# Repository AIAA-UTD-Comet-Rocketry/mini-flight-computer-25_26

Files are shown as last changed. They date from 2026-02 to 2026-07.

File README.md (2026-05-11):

# ESP32 Mini Flight Computer 25-26

Firmware for comet rocketry's flight computer built on the ESP32-S3 platform. The system handles sensor fusion, barometric altimetry, flight state management, pyrotechnic deployment, SD card logging, and CAN bus telemetry.

---

## Prerequisites

- ESP-IDF v5.5.x — [Official Installation Guide](https://docs.espressif.com/projects/esp-idf/en/latest/esp32/get-started/index.html)
- VSCode with the ESP-IDF extension (recommended) or any IDE with C/C++ support
- ESP32-S3 board to flash firmware

Build and flash:
```
idf.py build
idf.py erase-flash
idf.py flash monitor
```

---

## Hardware

**Microcontroller:** ESP32-S3

### Sensors (I2C)

| Sensor | Bus | Address | Function |
|---|-----|---|---|
| LSM6DSV80X | I2C0 (SDA=39, SCL=40) | 0x6A | 6-axis IMU — ±80g accelerometer + gyroscope |
| LPS22DF | I2C1 (SDA=41, SCL=42) | 0x5C | Barometric pressure / temperature |
| IIS2MDC | I2C1 (SDA=41, SCL=42) | 0x1E | 3-axis magnetometer |

### GPIO Pinout

| Function | GPIO |
|---|---|
| Pyro — Drogue 1 (35g CO2) | 6 |
| Pyro — Drogue 2 (45g CO2) | 7 |
| Pyro — Main 1 | 8 |
| Pyro — Main 2 | 9 |
| LED — Status | 1 |
| LED — CAN TX | 2 |
| LED — CAN RX | 4 |
| LED — SD TX | 10 |
| LED — SD RX | 11 |
| CAN RX (TWAI) | 36 |
| CAN TX (TWAI) | 37 |
| IMU INT1 | 38 |
| Baro INT | 46 |
| SD CLK | 34 |
| SD CMD | 47 |
| SD DATA0-3 | 48, 35, 21, 26 |

---

## Software Architecture

The firmware runs on FreeRTOS with five concurrent tasks at 100 Hz each. All sensor data is funnelled into a shared `FusedPacket_t` struct protected by a spinlock.

```
app_main()
│
├── BSP init (I2C, sensors, CAN, GPIO)
├── IMU calibration (NVS-backed, auto-sequence on first run)
├── Ground pressure calibration (1 s average)
│
├── Task: vImuHandlerTask    priority 2 — reads LSM6DSV80X, runs Madgwick AHRS
├── Task: vAltHandlerTask    priority 2 — reads LPS22DF, IIR filters pressure, computes altitude
├── Task: vFsmTask           priority 2 — runs flight state machine at 10 ms
├── Task: vSdLoggerTask      priority 1 — writes CSV to SD card at 100 ms
├── Task: LED_Task           priority 0 — drives LED blink patterns
├── Task: Pyro_Task          priority 4 — fires pyro channels on task notification
└── Task: CAN-TLM            priority 1 — broadcasts CANaerospace telemetry
```

### Sensor Pipeline

```
LSM6DSV80X (raw mg, mdps)
  └─► apply NVS calibration (offset + sensitivity)
  └─► axis remap (BOARD_AXIS_ALIGNMENT)
  └─► FusionBias (gyro bias estimation)
  └─► Madgwick AHRS (quaternion → Euler angles, earth-frame acceleration)
  └─► sensor_velocity_predict() (accel integration → vertical velocity)
  └─► FusedPacket_t { currAcc, currGyro, orientation, linearAcc, gTotalAcc }

LPS22DF (raw hPa)
  └─► hardware LPF at ODR/9 + 64-sample averaging (on-chip)
  └─► sensor_pressure_filter() — 2nd-order Butterworth IIR, fc=5 Hz
  └─► sensor_get_altitude() — ISA pressure-altitude formula (ft MSL)
  └─► sensor_velocity_correct() — complementary filter blends baro Δalt/Δt with accel velocity
  └─► FusedPacket_t { currPress, currTempF, gAltitude, gVerticalVelocity }
```

Calibration parameters (accel offset, accel sensitivity, gyro offset) are stored in NVS and loaded on boot. Re-running calibration requires enabling the `calibration_run_menu()` call in `app_main()`.

---

## Flight State Machine

The FSM runs in `vFsmTask` and progresses through the following states. All thresholds reference `gTotalAcc` (g), `gAltitude` (ft AGL), and `gVerticalVelocity` (ft/s).

```
IDLE ──► ARMED
          │
          │  gTotalAcc > 1.6 g  for 100 ms
          ▼
       BURNING
          │
          │  gTotalAcc < 1.3 g  OR  burn time > 4000 ms
          ▼
        RISING
          │
          │  3 consecutive descending velocity/altitude samples (500 ms period)
          ▼
        APOGEE ──► fires Drogue 1, then Drogue 2 (1000 ms delay)
          │
          │
          ▼
   DROGUE_DESCENT
          │
          │  gAltitude < 1500 ft → fires Main 1
          │  gAltitude < 1300 ft → fires Main 2 (backup)
          ▼
   MAIN_DESCENT
          │
          │  altitude change < 3 ft  OR  velocity < 8 ft/s  for 10 samples
          ▼
        LANDED
```

State transitions and pyro events are broadcast over CAN as event frames.

---

## SD Card Logging

Logs are written as CSV files on a FAT32 SD card mounted at `/sdcard` (4-bit SDMMC, up to 20 MHz).

**CSV columns:**

| Column | Unit |
|---|---|
| timestamp_s | seconds since boot |
| acc_x, acc_y, acc_z | g (calibrated, body-frame) |
| accel_g | total acceleration magnitude (g) |
| velocity_fps | vertical velocity (ft/s) |
| yaw_deg, pitch_deg, roll_deg | degrees |
| pressure_hpa | raw barometric pressure |
| altitude_ft | AGL altitude (ft) |
| temp_f | temperature (°F) |
| flight_state | FSM state enum value |
| drogue1, drogue2, main1, main2 | pyro fired flags (0/1) |

Log entries are written at 10 Hz. Files are synced every 10 writes to limit data loss on power failure.

---

## CAN Bus Telemetry (CANaerospace)

The system transmits on a 500 kbit/s CAN bus using the CANaerospace protocol (node ID 1). The following message IDs are broadcast at 1 Hz during flight:

| CAN ID | Content | Unit |
|---|---|---|
| 304–306 | Accel X/Y/Z | g |
| 320–322 | Pitch / Roll / Yaw | deg |
| 605 | Pressure altitude | ft |
| 1300 | FSM state | enum |
| 1301 | Status flags | bitfield |
| 1302 | Pyro fired status | bitfield |
| 1303 | Total acceleration | g |
| 1304 | Vertical velocity | ft/s |
| 1310 | Event frames (launch, apogee, pyro, etc.) | — |

Status flag bits (ID 1301): `SD_LOGGING`, `MAG_CAL_VALID`, `EKF_LOCKED`, `GROUND_PRESS_VALID`, `ARMED`.

---

## Libraries

### Custom Components (`components/`)

**FlightFSM**
State machine implementation. `FlightStateAdapter.c` defines entry/exit callbacks and transition conditions for all 9 flight states. Pyro channels are fired via `xTaskNotify` to `Pyro_Task` from state transition callbacks.

**CanAero**
CANaerospace protocol encoder/transmitter. Manages a pool of 8 TX frame slots returned via TWAI TX-done callbacks. `can_telemetry.cpp` drives a 1 Hz broadcast task; `canaerospace.cpp` handles frame construction and big-endian byte ordering per spec.

**Fusion** (Seb Madgwick)
Madgwick AHRS algorithm. Estimates 3D orientation as a quaternion from gyroscope, accelerometer, and optional magnetometer data. Features configurable acceleration and magnetic rejection, automatic bias estimation (`FusionBias`), and axis remapping (`FusionRemap`) to align the sensor board frame to the rocket body frame.

**IIS2MDC / LPS22DF / LSM6DSV80X**
ST Microelectronics sensor driver libraries. Provide register-level read/write abstraction over the BSP I2C wrappers. Drivers are integrated via callback function pointers (`ReadReg`/`WriteReg`) registered during `bsp_init()`.

### Managed Components (`managed_components/`)

**espressif/esp-dsp** v1.8.1
Espressif DSP library. Used for the `dsps_biquad_f32` biquad IIR filter applied to the raw barometric pressure. On ESP32-S3 the filter resolves to the hardware-accelerated AES3 vector variant. Coefficients are a 2nd-order Butterworth low-pass at fc = 5 Hz / fs = 100 Hz, computed with `scipy.signal.butter`.

### ESP-IDF Components (REQUIRES)

| Component | Purpose |
|---|---|
| `esp_driver_gpio` | LED and pyro GPIO output control |
| `esp_driver_i2c` | I2C master bus for sensor communication |
| `esp_driver_twai` | CAN bus (TWAI) transmit/receive |
| `esp_driver_sdmmc` | SD card host controller |
| `esp_timer` | High-resolution timestamps (`sensor_get_tick_ms`) |
| `fatfs` | FAT32 filesystem for SD card log files |
| `nvs_flash` | Non-volatile storage for IMU calibration parameters |
| `espcoredump` | Panic-time core dump to UART/Flash for crash diagnosis |

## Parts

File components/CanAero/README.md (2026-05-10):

# CanAero Telemetry Protocol

This document describes the current CANaerospace telemetry protocol used by the flight computer.

## Summary
- Transport: Classic CAN (8-byte payload)
- Encoding: CANaerospace header (4 bytes) + 4-byte payload
- Telemetry cadence: chosen by FSM state (1 Hz on ground, 10 Hz in flight)
- Packetization: one packed telemetry packet split across 6 frames

## Frame Map

Status set (sent every tick at the cadence chosen by FSM state):

Datum / Packet            | DTC     | Frame ID(s)       | Bytes | Notes
---|---|---|---|---
Telemetry packet chunk 0  | UCHAR4  | 1400              | 4     | bytes 0-3 of packed packet
Telemetry packet chunk 1  | UCHAR4  | 1401              | 4     | bytes 4-7
Telemetry packet chunk 2  | UCHAR4  | 1402              | 4     | bytes 8-11
Telemetry packet chunk 3  | UCHAR4  | 1403              | 4     | bytes 12-15
Telemetry packet chunk 4  | UCHAR4  | 1404              | 4     | bytes 16-19
Telemetry packet chunk 5  | UCHAR4  | 1405              | 4     | bytes 20-23

## Packed Telemetry Payload (24 bytes, little-endian)

Byte range | Type     | Field                | Scaling / Notes
---|---|---|---
0-3  | uint32 | time_ms            | ms since boot
4-5  | int16  | altitude_ft        | ft
6-7  | int16  | vert_vel_fps_x10   | ft/s * 10
8-9  | int16  | accel_x_mg         | g * 1000 (mg)
10-11| int16  | accel_y_mg         | g * 1000 (mg)
12-13| int16  | accel_z_mg         | g * 1000 (mg)
14-15| int16  | pitch_deg          | degrees
16-17| int16  | roll_deg           | degrees
18-19| int16  | yaw_deg            | degrees
20   | uint8  | fsm_state          | State enum value
21   | uint8  | status_flags       | bitmap below
22   | uint8  | pyro_status        | mirrors gPyroStatus
23   | uint8  | reserved           | 0

## Status Flags (status_flags byte)
- bit 0 SD_LOGGING_ACTIVE - sd_logger_is_active() returned true
- bit 1 MAG_CAL_VALID - NVS load succeeded at boot
- bit 2 EKF_LOCKED - EKF cal phase complete
- bit 3 GROUND_PRESSURE_VALID - baro ground cal succeeded
- bit 4 ARMED - FSM not in IDLE/DISARM
- bit 5..7 reserved (zero)

## Event Frames (unchanged)

ID 1310, DTC=UCHAR2
- byte 4: event_type
- byte 5: event_data

event_type | name           | data
---|---|---
0x01 | BOOT          | reset reason (esp_reset_reason() cast to u8)
0x02 | ARMED         | 0
0x03 | DISARMED      | 0
0x04 | LAUNCH        | peak gTotalAcc rounded to u8 (g)
0x05 | BURNOUT       | 0
0x06 | APOGEE        | 0
0x07 | DROGUE_FIRED  | 0
0x08 | MAIN_FIRED    | 0
0x09 | LANDED        | 0
0x10 | SENSOR_FAIL   | sensor ID (1=IMU, 2=MAG, 3=BARO)
0x11 | SD_FAIL       | 0
0xFF | GENERIC_ERROR | error code

## Notes
- Reassemble chunks in order 0..5 into a 24-byte buffer before decoding.
- All payload fields are little-endian.

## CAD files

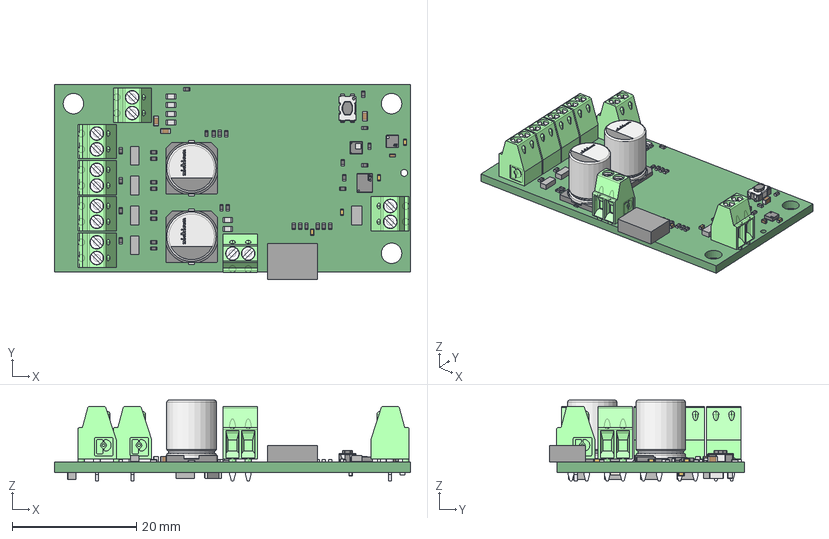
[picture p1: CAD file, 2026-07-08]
PCB docs/Main.step
57.4 x 31.4 x 13.0 mm
CAPC1608X95N EIA 0603 x 4
Mid_Body x 31
Mark x 31
Extruded x 23
mpt_0.5-2-2.54 x 7
Leads
Sub
Top
STMicroelectronics
circle
CAPC1005X60N EIA 0402
RES0603
STM Logo
STM Logo - 1
pin 1
logo x 2
shield
base x 2
terminals x 2
RES0402
Cap_Nichicon_UWT1C471MNL1GS_eec x 12

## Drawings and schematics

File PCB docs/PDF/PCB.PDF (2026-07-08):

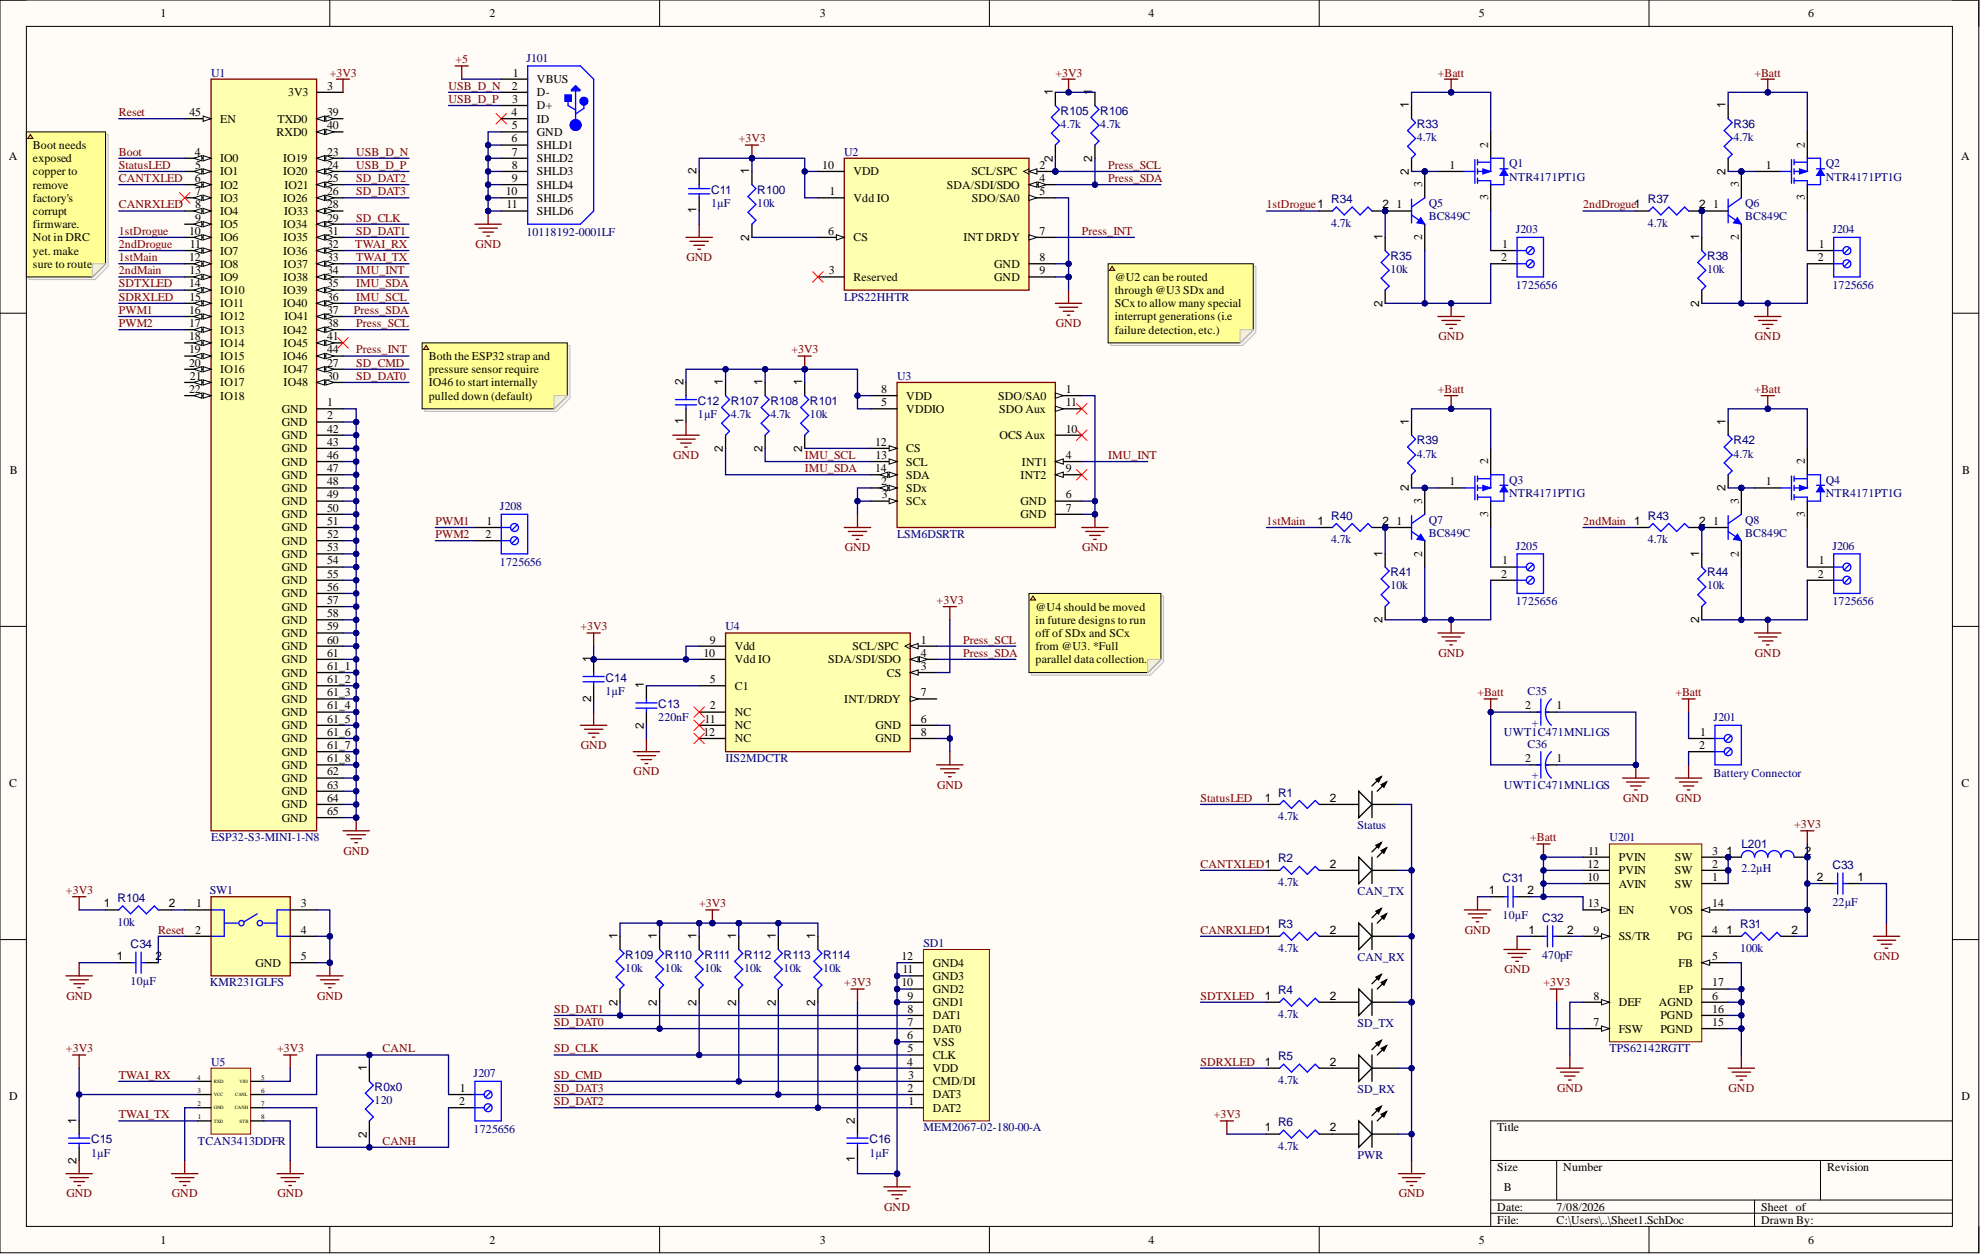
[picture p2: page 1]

corru
firmware. Not in DRC yet. make sure to route

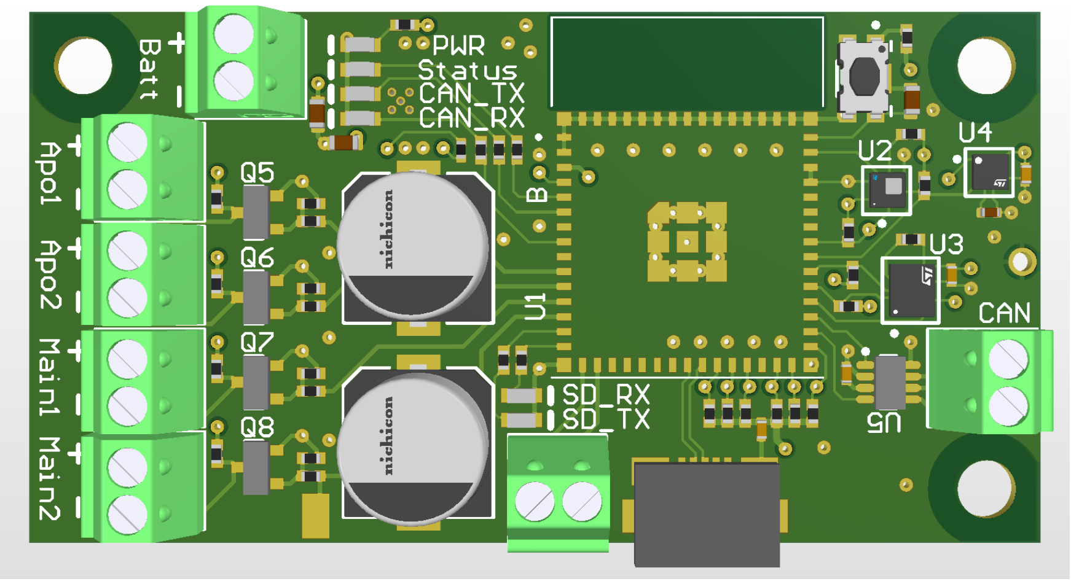
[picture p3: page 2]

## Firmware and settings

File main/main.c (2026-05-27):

/*
 * SPDX-FileCopyrightText: 2022-2024 Espressif Systems (Shanghai) CO LTD
 *
 * SPDX-License-Identifier: Apache-2.0
 */

#include "main.h"
#include <stdio.h>
#include <string.h>
#include <stdlib.h>
#include "sdkconfig.h"
#include "esp_log.h"
#include "driver/i2c_master.h"
#include "freertos/FreeRTOS.h"
#include "BSP.h"
#include "gpio_mgr.h"
#include "sd_logger.h"
#include "sensor_mgr.h"
#include "FlightFSM.h"
#include "can_telemetry.h"
#include "esp_timer.h"
#include "esp_system.h"
#include "nvs.h"
#include "nvs_flash.h"
#include "Fusion.h"
#include "imu_calibration.h"

// Macros
#define CHECK_TASK_CREATION(ret, err_msg) \
    if((ret) != pdPASS) { \
        ESP_LOGI(TAG, err_msg); \
    }
#define UTDMALLOC(n, els)              (els *) malloc((n)*sizeof(els))
#define MIN_STACK_SIZE          configMINIMAL_STACK_SIZE // original minimum causes stack overflow
#define SENSOR_SAMPLE_RATE_MS   10  // 1/10ms = 100Hz
#define LOGGING_SAMPLE_RATE_MS  100 // ms (10 Hz SD log cadence)
#define FSM_SAMPLE_RATE         10
#define BARO_CAL_CYCLES         500

// Uncomment to run pyro bench test on boot (DO NOT fly with this enabled)
//#define PYRO_BENCH_TEST

static const char *TAG = "MAIN";

static FlightState flight_state;
FusedPacket_ptr fusedData_p;
FusionAhrs ahrs;
FusionBias bias;

// use identity matrix to ensure no cross axis correction
FusionMatrix const FUSION_IDENTITY_MATRIX = {
    .array = {
    1.0f, 0.0f, 0.0f,
    0.0f, 1.0f, 0.0f,
    0.0f, 0.0f, 1.0f
    }
};

// Calibration parameters
FusionMatrix gyroscopeMisalignment = FUSION_IDENTITY_MATRIX; 
FusionVector gyroscopeSensitivity = {{1.0f, 1.0f, 1.0f}};
FusionVector gyroOffset = {{0.0f, 0.0f, 0.0f}}; // default to zero if no calibration found

FusionMatrix accelerometerMisalignment = FUSION_IDENTITY_MATRIX;
FusionVector accelSensitivity = {{1.0f, 1.0f, 1.0f}};
FusionVector accelOffset = {{0.0f, 0.0f, 0.0f}};

static void init_nvs_flash_memory(void);
static inline void fused_snapshot(FusedPacket_t *out);
uint32_t sensor_get_tick_ms(void);
static void load_params(void);
static void init_AHRS(void);
void sensor_update_flight_data(void);

// RTOS Tasks
static void vImuHandlerTask(void *pvParameters);
static void vAltHandlerTask(void *pvParameters);
static void vSdLoggerTask(void *pvParameters);
static void vFsmTask(void *pvParameters);

SemaphoreHandle_t xSemaphore;

BaseType_t task_ret;
TaskHandle_t xImuTaskHandle = NULL;
TaskHandle_t xAltTaskHandle = NULL;
TaskHandle_t xFsmTaskHandle = NULL;
TaskHandle_t xLEDTaskHandle = NULL;
TaskHandle_t xSdLoggerHandle = NULL;
TaskHandle_t xPyroTaskHandle = NULL;

// Spinlock guarding writes/reads of *fusedData_p. Held only for struct-field
// copies (microseconds), never across SD I/O.
static portMUX_TYPE g_fused_mux = portMUX_INITIALIZER_UNLOCKED;

void app_main(void) {
    (void)TAG; // Stop compile warnings, unused debug variables are not a concern

    fusedData_p = UTDMALLOC(1, FusedPacket_t);
    if (fusedData_p == NULL) {
        ESP_LOGE(TAG, "Failed to allocate fused packet buffer.");
        while (1) { vTaskDelay(pdMS_TO_TICKS(1000)); }
    }
    // Handle config
    static board_handle_t mini_fc_handle;

    bsp_config_t bsp_init_cfg = {
        .Bsp_GetTick = xTaskGetTickCount,
        .Bsp_Delay = vTaskDelay
    };

    if (bsp_init(&mini_fc_handle, &bsp_init_cfg) != ESP_OK) {
        ESP_LOGE(TAG, "BSP init failed. Stopping program!");
        LED_setPattern(led_can_rx, pattern_on);
        while (1) { vTaskDelay(pdMS_TO_TICKS(1000)); }
    }

    init_nvs_flash_memory();

    if(0) {
    vTaskDelay(pdMS_TO_TICKS(5000));
    calibration_run_menu(mini_fc_handle->lsm6dsv80x_handle, &accelOffset, &accelSensitivity, &gyroOffset);
    }

    load_params();
    init_AHRS();

    /// Flight State Machine
    initFlightState(&flight_state);
    registerFlightState(&flight_state);  // bind for getCurrentFlightState()

    // CAN telemetry up early so subsequent steps can fire status bits and events.
    can_telemetry_start(*mini_fc_handle->can_node_hdl);
    can_telemetry_event(EVT_BOOT, (uint8_t)esp_reset_reason());

    if (sd_logger_init() != ESP_OK) {
        can_telemetry_event(EVT_SD_FAIL, 0); // Send SD fail bit to CAN bus
    }
    
    // Semaphore init (guards FATFS calls in the SD logger task)
    xSemaphore = xSemaphoreCreateMutex();

    task_ret = xTaskCreate(vImuHandlerTask,
                           "IMU",
                           6 * MIN_STACK_SIZE,
                           (void*)mini_fc_handle->lsm6dsv80x_handle,
                           2,
                           &xImuTaskHandle);
    CHECK_TASK_CREATION(task_ret, "IMU task failed to create!");

    task_ret = xTaskCreate(vAltHandlerTask,
                           "Absolute Pressure Data Collection",
                           4 * MIN_STACK_SIZE,
                           (void*)mini_fc_handle->lps22df_handle,
                           2,
                           &xAltTaskHandle);

    task_ret = xTaskCreate(vFsmTask,
                           "Flight FSM",
                           4 * MIN_STACK_SIZE,
                           NULL,
                           2,  
                           (void*)&xFsmTaskHandle);
    CHECK_TASK_CREATION(task_ret, "FSM task failed to create!");
    if (task_ret == pdPASS && xFsmTaskHandle != NULL) {
        vTaskSuspend(xFsmTaskHandle); // Suspend task until sensors are stabilized
    }

    task_ret = xTaskCreate(vSdLoggerTask,
                            "SD Logger",
                            7 * MIN_STACK_SIZE,
                            NULL,
                            1,
                            (void*)&xSdLoggerHandle);
    CHECK_TASK_CREATION(task_ret, "SD Logger task failed to create!");
    if (task_ret == pdPASS && xSdLoggerHandle != NULL) {
        vTaskSuspend(xSdLoggerHandle); // Suspend task until sensors are stabilized
    }

    task_ret = xTaskCreate((TaskFunction_t)LED_Task, "LED MGR", 2 * MIN_STACK_SIZE, (void *)&mini_fc_handle, 0, &xLEDTaskHandle);
    CHECK_TASK_CREATION(task_ret, "LED task failed to create!");
    xTaskCreate((TaskFunction_t)Pyro_Task, "PYRO MGR", 2 * MIN_STACK_SIZE, (void *)&mini_fc_handle, 4, &xPyroTaskHandle);

    vTaskDelay(pdMS_TO_TICKS(5000)); // Wait for everything to settle (TODO event based wait)

    // drive led_status with pattern
    LED_setPattern(led_status, pattern_burst);

    #ifdef PYRO_BENCH_TEST
        // Bench test: fire each pyro channel one at a time with 3s gaps
        // Monitor GPIO 6,7,8,9 with multimeter/LED — DO NOT connect real charges
        ESP_LOGW(TAG, "=== PYRO BENCH TEST MODE ===");
        ESP_LOGW(TAG, "Firing channels in 5 seconds...");
        vTaskDelay(pdMS_TO_TICKS(5000));

        const char *channel_names[] = {"APO1 (35g CO2)", "APO2 (45g CO2)", "MAIN1 (TD2)", "MAIN2"};
        for (int ch = 0; ch < 4; ch++) {
            ESP_LOGW(TAG, "Firing channel %d: %s", ch, channel_names[ch]);
            xTaskNotify(xPyroTaskHandle, (1 << ch), eSetBits);
            vTaskDelay(pdMS_TO_TICKS(3000));
        }
        ESP_LOGW(TAG, "=== PYRO BENCH TEST COMPLETE ===");
        ESP_LOGW(TAG, "Pyro status bitmask: 0x%02X", gPyroStatus);
    #endif
}

static void init_AHRS(void) 
{
    FusionAhrsInitialise(&ahrs);

    const FusionAhrsSettings settings = {
        .convention = FusionConventionNwu,
        .gain = 0.5f,
        .gyroscopeRange = 250.0f,
        .accelerationRejection = 10.0f,
        .magneticRejection = 0, // mag sensor disabled
        .recoveryTriggerPeriod = 5 * (1000 / SENSOR_SAMPLE_RATE_MS), /* 500 samples in 5 sec */
    };
    FusionAhrsSetSettings(&ahrs, &settings);

    FusionBiasInitialise(&bias);
    FusionBiasSettings biasSettings = fusionBiasDefaultSettings;
    biasSettings.sampleRate = SENSOR_SAMPLE_RATE_MS;
    FusionBiasSetSettings(&bias, &biasSettings);

    ESP_LOGI(TAG, "Fusion AHRS Initialized.");
}

static void init_nvs_flash_memory(void) {
    esp_err_t err = nvs_flash_init();
    if (err == ESP_ERR_NVS_NO_FREE_PAGES || err == ESP_ERR_NVS_NEW_VERSION_FOUND) {
        // NVS partition was truncated and needs to be erased
        // Retry nvs_flash_init
        ESP_ERROR_CHECK(nvs_flash_erase());
        err = nvs_flash_init();
    }
    ESP_ERROR_CHECK( err );
}   

void vImuHandlerTask(void *pvParameters) 
{
    LSM6DSV80X_Object_t *imu = (LSM6DSV80X_Object_t *)pvParameters;
    LSM6DSV80X_Axes_t accel_axes, gyro_axes;
    FusionVector accel_axes_f, gyro_axes_f;

    ESP_LOGI(TAG, "Entering vImuHandlerTask...");

    while (1) {
        if (LSM6DSV80X_ACC_GetAxes(imu, &accel_axes) != LSM6DSV80X_OK) {
            ESP_LOGE(TAG, "Failed to obtain Accelerometer data!");
            continue;
        }
        if (LSM6DSV80X_GYRO_GetAxes(imu, &gyro_axes) != LSM6DSV80X_OK) {
            ESP_LOGE(TAG, "Failed to obtain Gyroscope data!");
            continue;
        }

        // mg -> g
        accel_axes_f.axis.x = (float)accel_axes.x / 1000.0;
        accel_axes_f.axis.y = (float)accel_axes.y / 1000.0;
        accel_axes_f.axis.z = (float)accel_axes.z / 1000.0;

        // mdps -> dps
        gyro_axes_f.axis.x = (float)gyro_axes.x / 1000.0;
        gyro_axes_f.axis.y = (float)gyro_axes.y / 1000.0;
        gyro_axes_f.axis.z = (float)gyro_axes.z / 1000.0;

        // Apply calibration
        FusionVector accel_cal = FusionModelInertial(
            accel_axes_f,
            accelerometerMisalignment,
            accelSensitivity,
            accelOffset
        );
        FusionVector gyro_cal = FusionModelInertial(
            gyro_axes_f,
            gyroscopeMisalignment,
            gyroscopeSensitivity,
            gyroOffset
        );

        // Remap sensor axes to rocket body frame.
        // No-op if BOARD_AXIS_ALIGNMENT is the default identity (PXPYPZ).
        accel_cal = FusionRemap(accel_cal, BOARD_AXIS_ALIGNMENT);
        gyro_cal = FusionRemap(gyro_cal, BOARD_AXIS_ALIGNMENT);

        // Update bias algorithm
        gyro_cal = FusionBiasUpdate(&bias, gyro_cal);

        // Calculate delta time to compensate for gyroscope sample clock errors
        const uint32_t timestamp = sensor_get_tick_ms();
        static uint32_t previousTimestamp;
        const float deltaTime = (float) (timestamp - previousTimestamp) / 1000.0f; 
        previousTimestamp = timestamp;

        // Update AHRS algorithm
        FusionAhrsUpdateNoMagnetometer(&ahrs, gyro_cal, accel_cal, deltaTime);

        /* Get AHRS Outputs */
        // Orientation (euler) angles (yaw, pitch, roll)
        const FusionEuler euler = FusionQuaternionToEuler(FusionAhrsGetQuaternion(&ahrs));
        // linear (earth) acceleration has gravity component removed
        const FusionVector earth = FusionAhrsGetEarthAcceleration(&ahrs); 
        sensor_velocity_predict(earth.axis.z, deltaTime);

        float totalAccG = sqrt(accel_cal.axis.x * accel_cal.axis.x + accel_cal.axis.y * accel_cal.axis.y + accel_cal.axis.z * accel_cal.axis.z);

        // Publish IMU-side fields into FusedPacket. Both producer tasks share
        // the spinlock; the SD logger snapshots the whole struct atomically.
        portENTER_CRITICAL(&g_fused_mux);
        fusedData_p->currTick_ms  = timestamp;
        fusedData_p->currAcc.axis.x    = accel_cal.axis.x;
        fusedData_p->currAcc.axis.y    = accel_cal.axis.y;
        fusedData_p->currAcc.axis.z    = accel_cal.axis.z;
        fusedData_p->currGyro.axis.x   = gyro_cal.axis.x;
        fusedData_p->currGyro.axis.y   = gyro_cal.axis.y;
        fusedData_p->currGyro.axis.z   = gyro_cal.axis.z;
        fusedData_p->orientation.angle.roll  = euler.angle.roll;
        fusedData_p->orientation.angle.pitch = euler.angle.pitch;
        fusedData_p->orientation.angle.yaw   = euler.angle.yaw;
        fusedData_p->linearAcc.axis.x = earth.axis.x;
        fusedData_p->linearAcc.axis.y = earth.axis.y;
        fusedData_p->linearAcc.axis.z = earth.axis.z;
        fusedData_p->gTotalAcc    = totalAccG;
        portEXIT_CRITICAL(&g_fused_mux);

        vTaskDelay(pdMS_TO_TICKS(SENSOR_SAMPLE_RATE_MS));
    }
}

static void vAltHandlerTask(void *pvParameters) 
{
    LPS22DF_Object_t *alt = (LPS22DF_Object_t *)pvParameters;
    AltData_t alt_data;
    float verticalVel = 0;
    uint16_t cycle_count = 0;
    bool flag = false;

    ESP_LOGI(TAG, "Entering vAltHandlerTask...");

    sensor_set_ground_pressure(SEA_LEVEL_PRESSURE_HPA);

    while(1) {
        if (LPS22DF_PRESS_GetPressure(alt, &alt_data.pressure) != LPS22DF_OK) {
            ESP_LOGE(TAG, "Failed to obtain Pressure data!");
            continue;
        }

        LPS22DF_TEMP_GetTemperature(alt, &alt_data.temp);

        // Filter pressure readings using 2nd order butterworth filter
        alt_data.pressure = sensor_pressure_filter(alt_data.pressure);
        alt_data.altitude = sensor_get_altitude(alt_data.pressure, alt_data.temp);
        sensor_velocity_correct(alt_data.altitude, sensor_get_tick_ms());

        alt_data.temp = alt_data.temp * 1.8 + 32.0; // Convert to F
        verticalVel = sensor_get_vertical_velocity();

        // Publish baro-side fields into FusedPacket.
        portENTER_CRITICAL(&g_fused_mux);
        fusedData_p->currPress = alt_data.pressure;
        fusedData_p->currTempF = alt_data.temp;
        fusedData_p->gAltitude = alt_data.altitude;
        fusedData_p->gVerticalVelocity = verticalVel;
        portEXIT_CRITICAL(&g_fused_mux);

        if (cycle_count == BARO_CAL_CYCLES && !flag) {
            vTaskResume( xSdLoggerHandle );
            vTaskResume( xFsmTaskHandle );
            flag = true;
        }
        cycle_count++;

        vTaskDelay(pdMS_TO_TICKS(SENSOR_SAMPLE_RATE_MS));
    }
}

static void vFsmTask(void *pvParameters) 
{
    (void)pvParameters;
    vTaskDelay(pdMS_TO_TICKS(5000));  // wait for sensors to settle

    ESP_LOGI(TAG, "Entering vFSMTask...");

    while (1) {
        sensor_update_flight_data();
        updateState(&flight_state);
        vTaskDelay(pdMS_TO_TICKS(FSM_SAMPLE_RATE));
    }
}

static void vSdLoggerTask(void *pvParameters) 
{
    LogSensorRecord_t record;
    FusedPacket_t snap;
    uint8_t print_counter = 0;
    uint32_t timeOffset = sensor_get_tick_ms();
    static bool loggingFlag;

    ESP_LOGI(TAG, "Entering vSDLoggerTask...");

    while (1) {
        vTaskDelay(pdMS_TO_TICKS(LOGGING_SAMPLE_RATE_MS));

        fused_snapshot(&snap);

        record.timestamp_s   = (float)(snap.currTick_ms - timeOffset) / 1000.0f;
        record.accel.axis    = snap.currAcc.axis;
        record.baro.pressure = snap.currPress;
        record.baro.temp     = snap.currTempF;
        record.orientation.angle   = snap.orientation.angle;
        record.baro.altitude = snap.gAltitude;
        record.gTotalAcc     = snap.gTotalAcc;
        record.gVertVelocity = snap.gVerticalVelocity;
        record.flightState   = getCurrentFlightState();
        record.pyroStatus    = gPyroStatus;

        if (record.flightState == STATE_DISARM && loggingFlag) {
            ESP_LOGI(TAG, "Rocket Landed. Stopping live telemetry logging...");
            sd_safe_unmount();
            LED_setPattern(led_sd_tx, pattern_off);
            loggingFlag = false;
        }
        loggingFlag = sd_logger_is_active();

        if (loggingFlag) {
            if (xSemaphoreTake(xSemaphore, portMAX_DELAY) == pdTRUE) {     
                write_packet(record);
                LED_setPattern(led_sd_tx, pattern_fast_blink);
                can_telemetry_set_status_bit(CAN_TLM_FLAG_SD_LOGGING, true);
                xSemaphoreGive(xSemaphore);
            }
        }
        else {
            can_telemetry_set_status_bit(CAN_TLM_FLAG_SD_LOGGING, false);
        }

        if (print_counter++ % 10 == 0) {
            ESP_LOGI("AHRS", "\tYaw: %d deg \tPitch: %d deg \tRoll: %d deg",
                (int)snap.orientation.angle.yaw, (int)snap.orientation.angle.pitch,
                (int)snap.orientation.angle.roll);
            ESP_LOGI("IMU", "\tAccel: \tX: %.1f, \tY: %.1f, \tZ: %.1f",
                snap.currAcc.axis.x, snap.currAcc.axis.y, snap.currAcc.axis.z);
            ESP_LOGI("IMU", "\tTotal Accel: %.1f g", snap.gTotalAcc);
            ESP_LOGI("BARO", "\tPress: %.1f hPa, \tTemp: %.1f F",
                snap.currPress, snap.currTempF);
            ESP_LOGI("BARO", "\tAltitude: %.1f ft", snap.gAltitude);
            ESP_LOGI("FUSION", "\tVertical Velocity: %.1f ft/s", snap.gVerticalVelocity);
        }
    }
}

// Atomic snapshot of the fused packet. Both producer tasks write
// under the same spinlock, so this copy is a coherent mix of the
// most recent IMU and baro samples.
static inline void fused_snapshot(FusedPacket_t *out) {
    portENTER_CRITICAL(&g_fused_mux);
    *out = *fusedData_p;
    portEXIT_CRITICAL(&g_fused_mux);
}

void sensor_update_flight_data(void) {
    gAltitude = fusedData_p->gAltitude;
    gVerticalVelocity_fps = fusedData_p->gVerticalVelocity;
    gTotalAcc = fusedData_p->gTotalAcc;
    gOrient[0] = fusedData_p->orientation.angle.yaw;
    gOrient[1] = fusedData_p->orientation.angle.pitch;
    gOrient[2] = fusedData_p->orientation.angle.roll;
    gAccel[0] = fusedData_p->currAcc.axis.x;
    gAccel[1] = fusedData_p->currAcc.axis.y;
    gAccel[2] = fusedData_p->currAcc.axis.z;
}

// Load calibrated params from NVS (if they exist).
static void load_params(void) 
{
    FusionVector loaded;
    
    if (cal_nvs_load("accel_offset", &loaded) == ESP_OK) {
        accelOffset = loaded;  // make these non-const
        ESP_LOGI(TAG, "Loaded accel offset from NVS");
    }
    if (cal_nvs_load("accel_sens", &loaded) == ESP_OK) {
        accelSensitivity = loaded;
        ESP_LOGI(TAG, "Loaded accel sensitivity from NVS");
    }
    if (cal_nvs_load("gyro_offset", &loaded) == ESP_OK) {
        gyroOffset = loaded;
        ESP_LOGI(TAG, "Loaded gyro offset from NVS");
    }
}

uint32_t sensor_get_tick_ms(void) 
{
    return (uint32_t)(esp_timer_get_time() / 1000);
}

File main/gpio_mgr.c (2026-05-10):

/*
 * File: gpio_mgr.h
 * 
 * Manages the low speed logic needed to drive the LED lights and pyro events.
 * The logic is wrapped into two RTOS tasks on the secondary core.
 * 
 * Created: 2025
 */

#include "gpio_mgr.h"
#include "esp_log.h"

#define PYRO_MAX_ATTEMPTS 2 // total allowed pyro drives
#define PYRO_DRIVE_TIME  50 // ms to drive pyro channel for
#define PYRO_COOL_TIME   500 // ms to wait between attempted drives

#define patternMax     160 // 125ms per sample so 20 seconds of to cycle through
#define patternBytes    20 // Each bit is a time sample

const uint8_t PATTERN_ALT_FUNC[patternBytes] = {
    0x00, 0x00, 0x00, 0x00, 0x00,
    0x00, 0x00, 0x00, 0x00, 0x00,
    0x00, 0x00, 0x00, 0x00, 0x00,
    0x00, 0x00, 0x00, 0x00, 0x00
}; // don't drive led from mgr task, 20 bytes allocated for memory safety

const uint8_t PATTERN_OFF[patternBytes] = {
    0x00, 0x00, 0x00, 0x00, 0x00,
    0x00, 0x00, 0x00, 0x00, 0x00,
    0x00, 0x00, 0x00, 0x00, 0x00,
    0x00, 0x00, 0x00, 0x00, 0x00
}; // off

const uint8_t PATTERN_ON[patternBytes] = {
    0xFF, 0xFF, 0xFF, 0xFF, 0xFF,
    0xFF, 0xFF, 0xFF, 0xFF, 0xFF,
    0xFF, 0xFF, 0xFF, 0xFF, 0xFF,
    0xFF, 0xFF, 0xFF, 0xFF, 0xFF
}; // on

const uint8_t PATTERN_SLOW_BLINK[patternBytes] = {
    0xFF, 0xFF, 0xF0, 0x00, 0x00,
    0xFF, 0xFF, 0xF0, 0x00, 0x00,
    0xFF, 0xFF, 0xF0, 0x00, 0x00,
    0xFF, 0xFF, 0xF0, 0x00, 0x00
}; // 2.5 sec on - 2.5 sec off

const uint8_t PATTERN_1SEC_BLINK[patternBytes] = {
    0xFF, 0x00, 0xFF, 0x00, 0xFF,
    0x00, 0xFF, 0x00, 0xFF, 0x00,
    0xFF, 0x00, 0xFF, 0x00, 0xFF,
    0x00, 0xFF, 0x00, 0xFF, 0x00
}; // 1 sec on - 1 sec off

const uint8_t PATTERN_FAST_BLINK[patternBytes] = {
    0x33, 0x33, 0x33, 0x33, 0x33,
    0x33, 0x33, 0x33, 0x33, 0x33,
    0x33, 0x33, 0x33, 0x33, 0x33,
    0x33, 0x33, 0x33, 0x33, 0x33
}; // 0.25 sec on - 0.25 sec off

const uint8_t PATTERN_VERY_FAST_BLINK[patternBytes] = {
    0x55, 0x55, 0x55, 0x55, 0x55,
    0x55, 0x55, 0x55, 0x55, 0x55,
    0x55, 0x55, 0x55, 0x55, 0x55,
    0x55, 0x55, 0x55, 0x55, 0x55
}; // 0.25 sec on - 0.25 sec off

const uint8_t PATTERN_1SEC_FLASH[patternBytes] = {
    0x01, 0x01, 0x01, 0x01, 0x01,
    0x01, 0x01, 0x01, 0x01, 0x01,
    0x01, 0x01, 0x01, 0x01, 0x01,
    0x01, 0x01, 0x01, 0x01, 0x01
}; // 0.125 sec on - 0.875 sec off

const uint8_t PATTERN_FAST_FLASH[patternBytes] = {
    0x11, 0x11, 0x11, 0x11, 0x11,
    0x11, 0x11, 0x11, 0x11, 0x11,
    0x11, 0x11, 0x11, 0x11, 0x11,
    0x11, 0x11, 0x11, 0x11, 0x11
}; // 0.125 sec on - 0.375 sec off

const uint8_t PATTERN_BURST[patternBytes] = {
    0x55, 0x00, 0x55, 0x00, 0x55,
    0x00, 0x55, 0x00, 0x55, 0x00,
    0x55, 0x00, 0x55, 0x00, 0x55,
    0x00, 0x55, 0x00, 0x55, 0x00
}; // 4 very-fast blinks - 1 sec off

const uint8_t PATTERN_TWOBLINK[patternBytes] = {
    0x55, 0x00, 0x55, 0x00, 0x55,
    0x00, 0x55, 0x00, 0x55, 0x00,
    0x55, 0x00, 0x55, 0x00, 0x55,
    0x00, 0x55, 0x00, 0x55, 0x00
}; // 2 fast blinks - 4 very-fast blinks

const uint8_t PATTERN_BAHDUM[patternBytes] = {
    0x0C, 0xFF, 0x0C, 0xFF, 0x0C,
    0xFF, 0x0C, 0xFF, 0x0C, 0xFF,
    0x0C, 0xFF, 0x0C, 0xFF, 0x0C,
    0xFF, 0x0C, 0xFF, 0x0C, 0xFF
}; // 0.5 sec off - 0.25 sec on - 0.25 sec off - 1 sec on

const uint8_t* g_patterns[pattern_max] = {
    PATTERN_ALT_FUNC,
    PATTERN_OFF,
    PATTERN_ON,
    PATTERN_SLOW_BLINK,
    PATTERN_1SEC_BLINK,
    PATTERN_FAST_BLINK,
    PATTERN_VERY_FAST_BLINK,
    PATTERN_1SEC_FLASH,
    PATTERN_FAST_FLASH,
    PATTERN_BURST,
    PATTERN_TWOBLINK,
    PATTERN_BAHDUM
};

static const char *pyro_channel_names[] = {
    [apo1_channel]  = "APO1 CHANNEL",
    [apo2_channel]  = "APO2 CHANNEL",
    [main1_channel] = "MAIN1 CHANNEL",
    [main2_channel] = "MAIN2 CHANNEL",
};

uint8_t* led_set_patterns[led_max];
static const char *TAG = "SensorMgr";
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

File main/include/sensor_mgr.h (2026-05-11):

/*
 * File: sensor_mgr.h
 *
 * Sensor calibration and data processing for the flight computer IMU.
 *
 * Created: 2025
 */

#ifndef SENSOR_MGR_H
#define SENSOR_MGR_H

#include <stdbool.h>
#include "esp_err.h"
#include "iis2mdc.h"
#include "lsm6dsv80x.h"
#include "lps22df.h"
#include "Fusion.h"

#define IMU_CAL_NUM_SAMPLES         500
#define MAG_CAL_NUM_SAMPLES         500
#define PRESS_CAL_NUM_SAMPLES       100
#define IMU_CAL_SAMPLE_DELAY_MS     10
#define MAG_CAL_SAMPLE_DELAY_MS     60
#define PRESS_CAL_SAMPLE_DELAY_MS   10
#define SEA_LEVEL_PRESSURE_HPA      1013.25

/**
 * Board-to-rocket axis alignment.
 * Letters describe how the SENSOR axes map to the BODY (rocket) axes:
 *   PXPYPZ = sensor +X→body +X, +Y→body +Y, +Z→body +Z (no remap)
 *   PYPZPX = sensor +Y→body +X, +Z→body +Y, +X→body +Z
 *   PZNYPX = sensor +Z→body +X, -Y→body +Y, +X→body +Z
 * etc.
 * The 24 entries cover every right-handed 90° axis-aligned rotation.
 * Pick the one that makes gravity (1 g pointing down on the pad) read on
 * body +Z when the rocket sits nose-up — that's the correct alignment.
 */
#ifndef BOARD_AXIS_ALIGNMENT
#define BOARD_AXIS_ALIGNMENT FusionRemapAlignmentPXPYPZ
#endif

typedef struct {
    float accel_g[3]; // calibrated accelerometer in g
    float gyro_dps[3]; // calibrated gyroscope in deg/s
    float mag_axes[3]; // calibrated mag axes
} imu_calibrated_t;

typedef struct {
    float pressure;
    float temp;
    float altitude;
} AltData_t;

typedef struct {
    float x;
    float y;
    float z;
} Sensor_Axes_t;

typedef struct {
    float roll;
    float pitch;
    float yaw;
} Euler_Angles_t;

// Shared flight data globals (updated by sensor tasks, read by FSM and SD logger)
extern float gTotalAcc;       // total acceleration magnitude in g
extern float gAltitude;       // barometric altitude AGL in feet
extern float gAccel[3];       // calibrated accelerometer (g)
extern float gGyro[3];        // calibrated gyroscope (dps)
extern float gOrient[3];
extern float gVerticalVelocity_fps;  // vertical velocity from baro (ft/s, +up)
extern uint8_t gPyroStatus;   // pyro fired bitmask (bit 0-3 = channels 1-4)

// Apply 2nd-order Butterworth IIR LPF (fc=5 Hz) to raw barometric pressure.
// Call from a single task only — state is not thread-safe.
float sensor_pressure_filter(float raw_hpa);

// Complementary filter on vertical velocity.
// earth_z_g is Fusion earth accel Z in g
// Predict: integrate earth z accel into gVerticalVelocity. Call
// from the 100 Hz IMU task with body-frame Z accel after axis remap.
// (NWU: positive = up)
void sensor_velocity_predict(float earth_z_g, float dt_s);

// Correct: pull gVerticalVelocity toward (Δalt/Δt) computed from
// consecutive baro samples. Call from the alt task after sensor_get_altitude.
void sensor_velocity_correct(float baro_altitude_ft, uint32_t tick_ms);

// Set ground-level reference pressure (call once at startup)
void sensor_set_ground_pressure(float pressure_hpa);

// Read the stored ground reference (used by alt task each cycle)
float sensor_get_ground_pressure(void);

// Slowly re-zero the stored ground pressure with one EMA step. The caller
// MUST only call this while the rocket is on the pad (FSM in IDLE/ARMED) —
// at apogee gTotalAcc is also ~1g, so any accel-based "at rest" gate is unsafe.
void sensor_track_ground_pressure(float pressure_hpa);

// Update gAltitude from current pressure reading
float sensor_get_altitude(float pressure_hpa, float temp);

float sensor_get_vertical_velocity(void);

// Update gTotalAcc, gAccel, gGyro from calibrated IMU data


#endif // SENSOR_MGR_H

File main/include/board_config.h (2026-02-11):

/*
 * File: board_config.h
 * 
 * This file contains macro defines to relating to the pin mappings of peripherals.
 * It is used to configure the board support package (BSP) for the mini flight computer.
 * 
 * Created: 2025
 */

 #ifndef BOARD_CONFIG_H
 #define BOARD_CONFIG_H

 //
// Board LED Definitions
//
#define LED_STATUS_GPIO_NUM GPIO_NUM_1
#define LED_STATUS_PIN LED_STATUS_GPIO_NUM
#define LED_STATUS_GPIO_MASK (1ULL << LED_STATUS_GPIO_NUM)

#define LED_CAN_TX_GPIO_NUM GPIO_NUM_2
#define LED_CAN_TX_PIN LED_CAN_TX_GPIO_NUM
#define LED_CAN_TX_GPIO_MASK (1ULL << LED_CAN_TX_GPIO_NUM)

#define LED_CAN_RX_GPIO_NUM GPIO_NUM_4
#define LED_CAN_RX_PIN LED_CAN_RX_GPIO_NUM
#define LED_CAN_RX_GPIO_MASK (1ULL << LED_CAN_RX_GPIO_NUM)

#define LED_SD_TX_GPIO_NUM GPIO_NUM_10
#define LED_SD_TX_PIN LED_SD_TX_GPIO_NUM
#define LED_SD_TX_GPIO_MASK (1ULL << LED_SD_TX_GPIO_NUM)

#define LED_SD_RX_GPIO_NUM GPIO_NUM_11
#define LED_SD_RX_PIN LED_SD_RX_GPIO_NUM
#define LED_SD_RX_GPIO_MASK (1ULL << LED_SD_RX_GPIO_NUM)


//
// PYRO Channel GPIO Definitions
//
#define PYRO_APO_1_GPIO_NUM GPIO_NUM_6
#define PYRO_APO_1_PIN PYRO_APO_1_GPIO_NUM
#define PYRO_APO_1_GPIO_MASK (1ULL << PYRO_APO_1_GPIO_NUM)

#define PYRO_APO_2_GPIO_NUM GPIO_NUM_7
#define PYRO_APO_2_PIN PYRO_APO_2_GPIO_NUM
#define PYRO_APO_2_GPIO_MASK (1ULL << PYRO_APO_2_GPIO_NUM)

#define PYRO_MAIN_1_GPIO_NUM GPIO_NUM_8
#define PYRO_MAIN_1_PIN PYRO_MAIN_1_GPIO_NUM
#define PYRO_MAIN_1_GPIO_MASK (1ULL << PYRO_MAIN_1_GPIO_NUM)

#define PYRO_MAIN_2_GPIO_NUM GPIO_NUM_9
#define PYRO_MAIN_2_PIN PYRO_MAIN_2_GPIO_NUM
#define PYRO_MAIN_2_GPIO_MASK (1ULL << PYRO_MAIN_2_GPIO_NUM)


//
// I2C Definitions
//
#define I2C_IMU_PORT I2C_NUM_0
#define I2C_IMU_SDA_GPIO_NUM GPIO_NUM_39
#define I2C_IMU_SDA_PIN I2C_IMU_SDA_GPIO_NUM
#define I2C_IMU_SCL_GPIO_NUM GPIO_NUM_40
#define I2C_IMU_SCL_PIN I2C_IMU_SCL_GPIO_NUM
#define I2C_IMU_INTERNAL_PULLUPS true
#define I2C_IMU_CLK_SPEED 100000 // 100 kHz

#define I2C_PRESS_PORT I2C_NUM_1
#define I2C_PRESS_SDA_GPIO_NUM GPIO_NUM_41
#define I2C_PRESS_SDA_PIN I2C_PRESS_SDA_GPIO_NUM
#define I2C_PRESS_SCL_GPIO_NUM GPIO_NUM_42
#define I2C_PRESS_SCL_PIN I2C_PRESS_SCL_GPIO_NUM
#define I2C_PRESS_INTERNAL_PULLUPS true
#define I2C_PRESS_CLK_SPEED 100000 // 100 kHz


//
// Sensor Definitions
//
#define SENSOR_IIS2MDC_I2C_ADDRESS (IIS2MDC_I2C_ADD >> 1) // 0x1E
#define SENSOR_IIS2MDC_CHIP_ID IIS2MDC_ID // 0x40U
#define SENSOR_IIS2MDC_I2C_PORT I2C_PRESS_PORT

#define SENSOR_LPS22DF_I2C_ADDRESS (LPS22DF_I2C_ADD_L >> 1) // 0x5C
#define SENSOR_LPS22DF_CHIP_ID LPS22DF_ID // 0xB4U
#define SENSOR_LPS22DF_I2C_PORT I2C_PRESS_PORT
#define SENSOR_LPS22DF_INT_GPIO_NUM GPIO_NUM_46
#define SENSOR_LPS22DF_INT_PIN SENSOR_LPS22DF_INT_GPIO_NUM

#define SENSOR_LSM6DSV80X_I2C_ADDRESS (LSM6DSV80X_I2C_ADD_L >> 1) // 0x6A
#define SENSOR_LSM6DSV80X_CHIP_ID LSM6DSV80X_ID // 0x73U
#define SENSOR_LSM6DSV80X_I2C_PORT I2C_IMU_PORT
#define SENSOR_LSM6DSV80X_INT1_GPIO_NUM GPIO_NUM_38
#define SENSOR_LSM6DSV80X_INT1_PIN SENSOR_LSM6DSV80X_INT1_GPIO_NUM


//
// CAN Definitions
//
#define CAN_RX_GPIO_NUM GPIO_NUM_36
#define CAN_RX_PIN CAN_RX_GPIO_NUM
#define CAN_RX_GPIO_MASK (1ULL << CAN_RX_GPIO_NUM)

#define CAN_TX_GPIO_NUM GPIO_NUM_37
#define CAN_TX_PIN CAN_TX_GPIO_NUM
#define CAN_TX_GPIO_MASK (1ULL << CAN_TX_GPIO_NUM)


//
// SD Card Definitions
//
#define SD_DATA0_GPIO_NUM GPIO_NUM_48
#define SD_DATA0_PIN SD_DATA0_GPIO_NUM
#define SD_DATA0_GPIO_MASK (1ULL << SD_DATA0_GPIO_NUM)

#define SD_DATA1_GPIO_NUM GPIO_NUM_35
#define SD_DATA1_PIN SD_DATA1_GPIO_NUM
#define SD_DATA1_GPIO_MASK (1ULL << SD_DATA1_GPIO_NUM)

#define SD_DATA2_GPIO_NUM GPIO_NUM_21
#define SD_DATA2_PIN SD_DATA2_GPIO_NUM
#define SD_DATA2_GPIO_MASK (1ULL << SD_DATA2_GPIO_NUM)

#define SD_DATA3_GPIO_NUM GPIO_NUM_26
#define SD_DATA3_PIN SD_DATA3_GPIO_NUM
#define SD_DATA3_GPIO_MASK (1ULL << SD_DATA3_GPIO_NUM)

#define SD_CLK_GPIO_NUM GPIO_NUM_34
#define SD_CLK_PIN SD_CLK_GPIO_NUM
#define SD_CLK_GPIO_MASK (1ULL << SD_CLK_GPIO_NUM)

#define SD_CMD_GPIO_NUM GPIO_NUM_47
#define SD_CMD_PIN SD_CMD_GPIO_NUM
#define SD_CMD_GPIO_MASK (1ULL << SD_CMD_GPIO_NUM)


 #endif // BOARD_CONFIG_H

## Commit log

2026-02-11 all WIP files
    [partitions_example.csv]
2026-03-06 [OVERHALL] Updating to FreeRTOS driven data collection
    [partitions_example.csv]
2026-03-06 Update README with ESP32 Mini Flight Computer details
    Added prerequisites and STM32 I2C sensors information to README.
2026-03-12 Added functional tests for all 3 sensor chips on the flight computer
2026-03-12 Added a Dockerfile that automates environment setup for the ESP SDK This dockerfile still misses the need for setting up the device to interact with the flight computer (ttyACM0)
2026-03-26 fix pyro charge
2026-03-27 Added SD card operation fixes to remount SD card when corrupted
    [main.c, sd_logger.c]
2026-05-03 Initialize IMUs and add Mag functions
2026-05-03 fix IMU calibration
2026-05-04 create working sensor fusion logic
2026-05-05 format data streams
    [log_00039.csv]
2026-05-10 switched to fusion library for IMU cal
2026-05-10 revamped calibration and data collection
2026-05-10 organized file struct
    [log_00117.csv]
2026-05-11 add IIR filter to baro
2026-05-11 add sd led status
2026-05-11 more revisions
    [dump1.txt, partitions.csv, partitions_example.csv]
2026-05-11 fix: atomically create and suspend FSM task
    Agent-Logs-Url: https://github.com/AIAA-UTD-Comet-Rocketry/mini-flight-computer-25_26/sessions/742aa400-a2e7-4fc5-94d1-1ede3a1c5ede
    [main.c]
2026-05-11 fix: harden FSM startup failure handling
    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
    [main.c]
2026-05-11 fix: clean up FSM task handle creation typing
    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
    [main.c]
2026-07-08 add pcb docs
    [Main.PcbDoc, Main.step, Sheet1.SchDoc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]
